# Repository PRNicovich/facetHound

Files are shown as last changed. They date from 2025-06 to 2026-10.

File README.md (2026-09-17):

# Facet Hound

Open hardware and software for the Facet Hound digital lapidary faceting machine.

Facet Hound is a mast-style faceting machine with digital readouts on all three axes, electronic indexing precise to less than 0.01 degrees, and a direct-driven lap powered by a brushless DC motor. It is designed to be replicated with readily available components and a minimum of custom parts. In 2025, the included components cost approximately $1,600.

Complete v7 and v8 assemblies are included as `Hardware/FacetHoundv7.step` and `Hardware/FacetHoundv8.step`. Subfolders of `Hardware/` contain vendor files for machining (`.step`, `.pdf`), 3D printing (`.stl`), PCB fabrication (`.brd`), and laser/plasma/waterjet cutting (`.dxf`). Commercially available parts are identified in the main design.

Subfolders of `Software/` contain the Arduino C++ sketches and desktop Python tools. The main module is a Raspberry Pi Pico 2, while peripheral controllers use RP2040 Zero boards.

## Current firmware

The current Pico 2 base plus RP2040 Zero mast, display, and keyboard-host
release is in
[`Software/FacetHound_SD_Loader`](Software/FacetHound_SD_Loader). It includes:

- Classic, Dynamic, and Static HX8357D display modes.
- A twist-wheel settings UI for machine and display configuration.
- Persistent CW/CCW indexing, Table Adapter, servo, calibration, and axis settings.
- Variable-length mark points with direct numeric editing.
- GemCad `.asc` and Facet Hound `.fct` loading from microSD.
- Source-validated `.fhc` geometry caching and a PC bulk converter.
- Runtime convex-gem mesh generation on the Pico 2 and streaming to the display.
- A documented USB CDC API and PC diagnostic/motion-test console.
- Matching streaming mast telemetry for tip, index, and force sensing.
- A dedicated PIO-USB keyboard host with the matching UART key protocol.

See the [release README](Software/FacetHound_SD_Loader/README.md) for SD wiring, dependencies, flashing instructions, limits, and verification results.

## Repository map

- `Hardware/`: complete assemblies and fabrication files.
- `Software/FacetHound_SD_Loader/`: current four-controller firmware release.
- `Software/caseModule/` and `displayModule/`: earlier module sketches.
- `Software/gemUtils/`: GemCad parsing, display prototypes, and geometry utilities.
- `Software/engraveUtils/`: engraving experiments.

These designs remain preliminary and may contain incomplete or untested elements. Contributions and bug fixes are welcome as pull requests.

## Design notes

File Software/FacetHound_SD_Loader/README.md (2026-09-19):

# Facet Hound SD loader build

This package contains the matching base, mast, display, and USB keyboard-host
firmware for loading GemCad designs from a microSD card through Display
Settings and operating the Facet Hound hardware as one system.

## Source targets

The complete Arduino sources are in `baseChassisModule/` for the Raspberry Pi
Pico 2 base, `mastModule/` for the Waveshare RP2040 Zero sensor module, and
`displayModule_v6_gem/` for the Waveshare RP2040 Zero display with the existing
HX8357D wiring. The dedicated keyboard host is in `usbToUART/`. Build and board
settings for all four controllers are collected in `FLASHING.md`.

See `INTEGRATION_TEST.md` for the staged three-module bring-up procedure and
short-circuit isolation checklist. The mast's exact UART contract and sensor
ranges are documented in `mastModule/README.md`.

## SD hookup

| microSD reader | Base GPIO |
| --- | ---: |
| CS | 10 |
| MOSI | 11 |
| SCK | 12 |
| MISO | 13 |

This is the connector order routed by `Hardware/pcb/v9/BaseModule.sch`.
Because it is not a legal hardware-SPI mapping, the firmware
uses Arduino-Pico's PIO-backed `SoftwareSPI`. The active motor link uses GPIO
8/9 at the v9 `ESC.TTL` header and an external automatic-direction RS-485
module; GPIO 26/27 are not routed on the v9 board.

Use a FAT16/FAT32 card. Put `.asc` or `.fct` files in its root, insert it, then
open **Settings -> Load SD design**. Scroll with the twist wheel and click to
load. The existing next/previous mark controls then walk the file's cuts in
GemCad order and home the index axis to the selected cut.

On first load the base looks for a same-named `.fhc` geometry cache. A cache is
used only when its format version, source byte count, and source CRC32 match.
Otherwise the Pico rebuilds the geometry and writes a fresh cache beside the
source. For example, `round.asc` produces `round.fhc`. Prebuild one file or a
whole folder on a PC with `tools/bulk_convert_gems.py` so the Pico only needs to
validate and load the cache.

Classic mode shows `T<tier> F<facet>`, signed target angle, and index in the
mark row. Dynamic/static gem modes show the loaded title and target angle/index
in the header/HUD. The first imported GemCad name in a tier is propagated to
all of that tier's facets, so labels such as `C1`, `C2`, `P1`, and `G2` remain
beside the tip angle throughout the tier; an unnamed table cut is shown as `T`.
GemCad center-to-facet distance is used only as the plane equation distance
during mesh construction; it is not machine Z and is never shown or commanded
as a Z target.

Without an SD design, Dynamic and Static navigate the built-in display gem.
The base carries its compact facet-pose table and sends an exact `@JOB` record,
so keyboard tier/facet changes select the target face instead of inferring a
face from the current encoder pose. Facets advance by increasing machine index
within each tier; tier changes begin at that tier's lowest index.

The Pico 2 now rebuilds the loaded design's 3D wireframe by incrementally
clipping a convex mesh against the GemCad half-space planes, then streams it to
both dynamic and static display modes. Redundant planes are skipped without
testing plane triples, and an adaptive temporary cube is never retained in the
result. The compiled `gem_data.h` design remains only as a startup/failure
fallback. Geometry is bounded at 512 planes, 1,024 vertices, and 2,048 edges.
Loading still does not command mast or Z motion; index selection uses the
existing twist control and safety behavior.

Settings also now includes encoder-zero actions (index, tip, Z, or all), Z-axis
polarity, flow conversion calibration in mL/min per raw flow tick, and a Special
Commands page for signed 0.01-10 RPM constant index spin. Spin stops on page
exit and times out if the display keepalive disappears.

See `baseChassisModule/SD_GEM_LOADER.md` for the parser behavior, cache format,
`.fct` coordinate format, limits, and serial protocol. See
`baseChassisModule/BASE_WIRING_AND_TEST.md` for the full pin map, dedicated
keyboard UART, and USB CDC bench console. The underlying PC control protocol is
documented in `baseChassisModule/PC_USB_API.md` so future software can drive the
base directly without depending on the supplied console UI.

## Verification

- Base source compiled with Arduino-Pico 5.6.0 for Raspberry Pi Pico 2:
  172,876 bytes flash; 16,392 bytes static RAM.
- Mast source compiled with Arduino-Pico 5.6.0 for Waveshare RP2040 Zero:
  60,972 bytes flash; 9,672 bytes static RAM.
- Keyboard USB-host source compiled with Arduino-Pico 5.6.0 for Waveshare
  RP2040 Zero at 240 MHz, `-O`, and Adafruit TinyUSB: 90,308 bytes flash;
  33,004 bytes static RAM.
- Display source compiled with Arduino-Pico 5.6.0 and the existing HX8357D
  flags: 392,832 bytes flash; 29,228 bytes static RAM.
- The reference `gemLoader.py` was exercised against nine supplied ASC
  fixtures (22 to 240 cuts; 64/80/96 wheels), including continuation lines,
  fractional indexes, and named facets.
- The double-precision convex-clipper mirror reproduced all nine reference
  fixtures exactly in topology. The largest had 240 planes, 466 vertices, and
  704 edges; maximum nearest-vertex error was `3.44e-14` model units.

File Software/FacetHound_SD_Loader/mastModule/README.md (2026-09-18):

# Mast module

This is the current mast firmware packaged beside the matching
`baseChassisModule` and `displayModule_v6_gem` projects. It is built for the
Waveshare RP2040 Zero with the Arduino-Pico core and the `RunningAverage`
library.

## Pin map

| Function | Mast GPIO |
|---|---:|
| Force sensor analog input | 28 |
| Tip encoder CS / DATA / CLOCK | 14 / 12 / 13 |
| Twist encoder CS / DATA / CLOCK | 15 / 7 / 6 |
| UART TX to base | 8 |
| UART RX from base | 9 |

The UART is 3.3 V TTL at 115200 baud. Connect mast TX GPIO8 to base RX GPIO2,
mast RX GPIO9 to base TX GPIO3, and connect grounds. Do not connect either UART
signal to RS-232 voltage levels.

## Base protocol compatibility

The current base consumes newline-terminated ASCII records:

```text
@tip,47850
@twist,2048
@force,3200
```

The mast reports every 20 ms. A received `?` also requests an immediate snapshot.
`@encfault` is a bit mask: 0 = both checksums good, 1 = tip invalid,
2 = index invalid, 3 = both invalid. Invalid encoder readings are omitted;
old averaged values are not reissued as fresh feedback. The base disarms
index lock on invalid index feedback. `encoder_fault=-1` in base STATUS means
the mast has not yet supplied this health record.

After upgrading from the legacy tip decoder, re-zero the tip at a known
reference: the old decoder included checksum bits in its position value.

The immediate snapshot preserves compatibility with the older polling base.
The active base does not need to poll.

| Record | Mast range | Base expectation | Result |
|---|---:|---:|---|
| `@tip` | 0-131064 | 131072 counts/revolution | Compatible |
| `@twist` | 0-4095 | 4096 counts/revolution | Compatible |
| `@force` | 0-131040 | accepted through 140000 | Compatible |

Twist uses a circular average, so samples around the 4095/0 boundary do not
average incorrectly through the middle of the wheel. Tip and force retain the
classic oversampled ranges used by existing calibration values. The machine
UART does not depend on USB. Telemetry is also mirrored to USB only when the
mast's USB CDC port is actively open during boot; USB power by itself does not
enable diagnostic mirroring.

The AMT23 SSI response begins with two parity/check bits. The 14-bit tip
position is taken from the low 14 bits before being scaled by eight for the
legacy base-module range. The 12-bit twist position is shifted right by two
because that mode supplies two low padding bits.

The firmware does not wait for any sensor to identify itself. With sensors
unplugged it continues sending frames, although the floating input values are
not meaningful. This permits UART integration testing before installing the
sensors.

The obsolete mast protocol used space-delimited `i`, `l`, and `e` records only
after receiving `?`. That format is not accepted by the current base and is no
longer emitted.

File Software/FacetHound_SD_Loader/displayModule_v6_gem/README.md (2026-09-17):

# Facet Hound RP2040 display v6

This Arduino-Pico firmware runs the 320 x 480 HX8357D display on the legacy
RP2040 Zero wiring. It provides three persisted boot modes:

- `CLASSIC`: the original machine-status UI and custom fonts.
- `DYNAMIC`: a smoothly animated gem wireframe driven by live machine pose.
- `STATIC`: TOP, BOTTOM, FRONT, and SIDE gem diagrams.

The firmware listens to the instrument UART and USB CDC simultaneously. Both
use the existing newline-delimited `@KEY,value` protocol, so the USB connection
is also the proxy/test input; no alternate firmware image is necessary.

The instrument UART uses a 512-byte receive queue so rendering cannot discard
short bursts from the base. Before normal telemetry begins, the base sends
`@PING,BASE`; the display answers `@PONG,BASE` to prove both UART directions.

When the display's own USB CDC port is open during boot, it begins with a
roughly 3.3-second animated splash. An installed display without an active USB
session goes directly to its persisted UI. The compiled
fallback gem is shown as a neutral, depth-cued wireframe at the C1 mast angle
and rotates at constant index speed. After about 0.9 seconds, the colored
`FACET HOUND` title fades in over the gem and remains for about 2.4 seconds
while rotation continues. A small centered
`A product of Advanced Precision Technologies, LLC` credit accompanies the
title at the bottom; the selected persisted UI then starts normally.

A transient settings menu overlays any of the three screens. It currently edits
display mode and is structured for later base-module settings.

## Hardware and Arduino setup

Use Earle F. Philhower's **Arduino-Pico** core and install:

- TFT_eSPI
- PioEncoder

`SerialPIO` is supplied by Arduino-Pico. Select the RP2040 Zero-compatible
board definition and use the normal 133 MHz CPU setting initially.

The legacy pin assignment is unchanged:

| Function | GPIO |
| --- | ---: |
| TFT SCLK | 2 |
| TFT MOSI | 3 |
| TFT CS | 5 |
| TFT DC | 6 |
| TFT RESET | 7 |
| Instrument UART TX | 8 |
| Instrument UART RX | 9 |
| Encoder | 10 |

TFT_eSPI compiles its driver configuration as part of the library, rather than
from the sketch. Back up the library's current `User_Setup.h`, then use
`User_Setup_HX8357D_RP2040.h` from this directory as its setup. It selects the
HX8357D driver, these pins, and the proven 62.5 MHz SPI setting.

Open `displayModule_v6_gem.ino` in Arduino IDE and upload it. The first boot
uses `CLASSIC`; later selections are stored in flash.

The packaged project also includes `displayModule_v6_gem_HX8357D.uf2`, already
compiled for the Waveshare RP2040 Zero with the exact HX8357D settings above.
To use it, hold BOOT while connecting/resetting the RP2040, then copy the UF2
onto the `RPI-RP2` drive. Building from source is preferable after changing the
embedded gem or UI.

## Select a screen

Send one of these commands through either the instrument UART at 460800 baud or
the USB serial port:

```text
@MODE,CLASSIC
@MODE,DYNAMIC
@MODE,STATIC
```

A changed mode is committed to flash and the RP2040 reboots. Query the current
mode without rebooting with:

```text
@MODE,?
```

Numeric aliases `0`, `1`, and `2` mean classic, dynamic, and static.

## Settings menu

Open the menu and navigate it through either serial connection:

```text
@MENU,TOGGLE
@MENUKEY,UP
@MENUKEY,DOWN
@MENUKEY,SELECT
@MENUKEY,BACK
```

The menu asks the base for one settings snapshot with `@CFGGET,ALL` when it
opens. Edits use `@CFGSET,id,value` or `@CFGACTION,id,value`, followed by a base
reply. Settings do not stream continuously. Long mark-point lists are fetched
in eight-value pages while that screen is visible. See `SETTINGS_PROTOCOL.md`
for the implemented base-module contract and physical control mapping.

The settings UI includes display mode, CW/CCW index direction, Table Adapter
(subtracts 45 degrees from the reported tip angle), automatic servo enable,
wheel index, Z polarity, flow conversion calibration, encoder-zero actions,
Special Commands with constant index spin, reset spacing, an SD design browser,
and direct numeric editing of a variable-length mark-point list. The card is attached to the base module;
the display requests six-name pages and loads a selected `.asc` or `.fct` file
through the settings protocol.

## USB proxy/testing

Install pyserial on the laptop:

```powershell
py -m pip install pyserial
```

Run animated test telemetry (replace `COM7`):

```powershell
py usb_proxy_test.py COM7 --demo 30
```

Change mode:

```powershell
py usb_proxy_test.py COM7 --mode dynamic
```

Or start an interactive protocol terminal:

```powershell
py usb_proxy_test.py COM7
```

The display sends encoder updates to both outputs as `@ZENC,count`.

For a visual test that runs directly in Spyder, open and run
`settings_menu_spyder.py`. It uses Matplotlib and can run with or without serial
hardware. `SERIAL_PORT = "AUTO"` selects a lone RP2040/USB serial device; replace
it with an explicit value such as `"COM5"` if several ports are connected, or
use `None` for a local-only preview. It now mirrors every firmware settings page. Arrow keys emulate
twist-wheel rotation, Enter is wheel click, Backspace is the top-left key,
`F`/`C` change edit tier, Delete removes a mark point, and `M` opens/closes the
menu. Press `D` or click **LIVE DEMO** to close Settings and stream moving
tip/index/Z telemetry so Dynamic mode visibly animates.

## Replace the embedded gem

`gem_data.h` contains the startup fallback mesh. When the base loads an ASC/FCT
design, the Pico 2 calculates the convex solid and streams its vertices, edges,
and facet ownership to this display. Dynamic mode rotates those runtime 3D
vertices; static mode projects the same runtime vertices into its four panels.

From a checkout containing `gemUtils/gem_generator.py`, run:

```powershell
py export_gem_data.py path\to\design.asc gem_data.h --gem-utils path\to\gemUtils
```

Rebuild and upload the sketch after regenerating the fallback header. The
supplied fallback was generated from `pc01391.asc` (`PC 01.391 Rings of Fire`).

Runtime SD jobs replace the displayed wireframe after a complete mesh transfer,
as well as replacing the machine cut sequence. GemCad center-to-facet distance
is used as a plane equation term during geometry construction, but it remains
unrelated to machine Z and is not shown as a Z target.

GemCad `n` names are treated as tier labels: the first name found in a tier is
shown for every facet in that tier (`C1`, `C2`, `P1`, `G2`, and so on). With a
runtime wireframe loaded, the large tip value is the tier target and the small
value is live tip error. Unnamed tiers are inferred as table, crown, pavilion,
or girdle from their geometry. Static view edges and the moving wireframe use
depth cueing; the lower HUD uses direction, RPM-unit, and flow-unit icons.

## Protocol mapping used by gem modes

- `T`: target index position.
- `E`: signed index error; live index is reconstructed as `T + E`.
- `TIP`: live tilt angle.
- `WIDX`: machine index-wheel resolution (normalized to the active runtime or
  fallback design).
- `ZMM`, `RPM`, `RPV`, `DIR`, `FLW`, `FLD`, and force `F`/`N`: lower HUD.

The large RPM readout shows the commanded setpoint while the lap is paused and
the measured `RPV` value while it is running. Flow is a commanded/calibrated
setpoint because the current hardware has no independent flow-rate sensor.

All other legacy fields continue to be parsed for classic mode.

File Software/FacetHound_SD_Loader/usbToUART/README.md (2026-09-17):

# USB keyboard-to-UART module

This dedicated RP2040 Zero module is the machine's USB host for the physical
keyboard. It keeps USB host behavior off the base Pico and translates new HID
key presses into the base module's simple 3.3 V UART protocol.

## Wiring

| Function | Bridge GPIO | Connects to |
|---|---:|---|
| PIO USB host D+ | 2 | Keyboard USB D+ |
| PIO USB host D- | 3 | Keyboard USB D- |
| UART TX | 0 | Base keyboard RX GPIO6 |
| UART RX | 1 | Base keyboard TX GPIO7 |
| Ground | GND | Base and keyboard-supply ground |

The keyboard also needs a correctly protected 5 V VBUS supply from the host
hardware. D+/D- are not power pins. Confirm VBUS polarity, grounding, current
protection, and the PCB's USB connector orientation before attaching a keyboard.
The UART side is 3.3 V TTL at 115200 baud, not RS-232.

## UART protocol

Each newly pressed HID usage is emitted on its own newline-terminated record:

```text
D,4
D,17
```

The active base consumes this format directly in `keyboardTask()`. Releases
are not sent. Already-held keys are suppressed when another key changes, and a
multi-key report produces one record for each newly pressed key. Non-keyboard
HID interfaces are ignored without stalling the USB host endpoint.

The bridge also emits an idle health record once per second while its USB-host
core is responsive:

```text
@HELLO,KEYBOARD
```

The base consumes this internally and reports `keyboard_link=up`; it never
treats the heartbeat as a key press.

The physical layout and HID assignments are in
[keyboardSettings.png](keyboardSettings.png). Operator functions are mapped in
[`../baseChassisModule/KEYBOARD_MAP.md`](../baseChassisModule/KEYBOARD_MAP.md).

## Required Arduino settings

Use Arduino-Pico 5.6.0 with these board selections:

| Setting | Value |
|---|---|
| Board | Waveshare RP2040 Zero |
| CPU speed | 240 MHz (Overclock) |
| Optimize | Optimize (`-O`) |
| USB stack | Adafruit TinyUSB |
| Flash | 2 MB, no filesystem |

The PIO USB host was originally validated with the 240 MHz and `-O` settings;
do not silently substitute the board defaults. The firmware uses core 1 for
the host task and restarts that core if its heartbeat stops for three seconds.

Verified Arduino CLI target:

```text
rp2040:rp2040:waveshare_rp2040_zero:freq=240,opt=Optimize,usbstack=tinyusb
```

Current compile size: 90,308 bytes flash and 33,004 bytes static RAM.

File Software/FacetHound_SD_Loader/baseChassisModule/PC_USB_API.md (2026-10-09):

# Base-module PC USB API

The base firmware exposes a line-oriented control and telemetry API over the
Pico's native USB CDC serial port. `tools/base_module_console.py` is a reference
client, not a required intermediary: another PC program can open the same COM
port and send these commands directly.

This API is separate from the dedicated keyboard UART on GPIO 6/7 and from the
base-to-display UART. Using USB CDC does not reconfigure either hardware link.

At startup the base probes the display on the unchanged TX5/RX4 pins, first at
uiReno's 38400 baud, then at 460800 for installed fast-display firmware. Each
rate gets a 3-second window with an existing `@PING,<token>` probe every 250 ms.
Only the matching `@PONG,<token>` confirms the rate; received byte counts and
unsolicited messages do not. USB reports `@DISPLAY_LINK,TRY,baud=...` and
`@DISPLAY_LINK,READY,baud=...`. Saved-gem restoration and model transmission wait
for confirmation. Probing repeats if neither rate answers, but never changes
the rate after confirmation. Mast/keyboard ports and display firmware are not
reconfigured. Continued TRY messages mean no round trip at either supported
rate, not a geometry-parser failure.

Restoring the saved gem does not rewrite its already-saved SD selection marker;
new selections still save normally. After loading, three bounded PING attempts
test the existing link before model metadata/cache/mesh transmission. USB reports
`@GEM,POSTLOAD_PING_OK` or `@GEM,DISPLAY_ERROR,POSTLOAD_PING_TIMEOUT`.
No UART resets or baud changes occur during this post-load test.

## Transport and framing

- USB CDC serial, conventionally opened as 115200 baud, 8-N-1. USB CDC does
  not physically depend on that baud rate, but clients should use 115200 for
  consistency with the supplied console.
- Commands and responses are printable ASCII terminated by `\n`.
- The firmware accepts `\r\n` and ignores `\r`.
- Commands are case-insensitive and fields are separated by spaces.
- Maximum accepted command line is 127 bytes, excluding the terminator.
- Replies beginning with `@ACK` indicate acceptance, `@ERR` indicates a bad
  command or argument, and `@STATE` / `@IO` are telemetry.

The port also carries boot diagnostics, cache messages, and asynchronous
`@KEY,<hid>` records. Clients should therefore parse by prefix and ignore
unknown lines for forward compatibility.

## Commands

| Command | Meaning | Typical reply |
|---|---|---|
| `HELP` | List commands supported by the running firmware | One or more `@HELP,...` lines |
| `STATUS` | Emit one complete state and I/O snapshot | `@STATE,...` then `@IO,...` |
| `LINKCHECK` | Two receive-path snapshots one second apart, without restarting UARTs or consuming their input | `@LINKCHECK`, `@RXCHECK`, `@RXPIO` |
| `STREAM ON [ms]` | Stream snapshots every 50-5000 ms; default 250 ms | `@ACK,STREAM,ON` |
| `STREAM OFF` | Stop periodic snapshots | `@ACK,STREAM,OFF` |
| `PROBE` | Immediately query the mast, display, and lap Modbus links | `@ACK,PROBE,MAST_DISPLAY_AND_LAP` |
| `TRACE ON` / `TRACE OFF` | Mirror complete incoming peripheral UART lines to PC USB | `@ACK,TRACE,ON/OFF` |
| `TEST DISPLAY ON` | Send changing synthetic values to the display without changing machine state | `@ACK,TEST,DISPLAY,ON` |
| `TEST DISPLAY OFF` | Restore normal machine telemetry | `@ACK,TEST,DISPLAY,OFF` |
| `TEST DISPLAY LOOPBACK` | Five-second base GPIO4/5 loopback test | `@ACK,TEST,DISPLAY,LOOPBACK,5_SECONDS` |
| `KEY <0..255>` | Inject one configured HID usage through the same action router as the UART keyboard | `@ACK,KEY,<hid>` |
| `JOG TWIST <index-units>` | Set a relative index target and enable index lock | `@ACK,JOG,TWIST,<target>` |
| `INDEX PROBE` | Explicit motion test: 128 positive STEP pulses at 300 pulses/s maximum, then sample encoder delta and release; requires fresh valid encoders, axes unlocked and lap paused | `@INDEX_PROBE,...,suggested_motor_sign=...` (does not change calibration) |
| `JOG Z <signed-steps>` | Request a relative Z move in raw motor steps | `@ACK,JOG,Z,<steps>` |
| `RPM <0..1500>` | Set lap-speed command in RPM (no automatic startup boost) | `@ACK,RPM,<rpm>` |
| `MOTOR CW` | Set lap direction clockwise | `@ACK,MOTOR` |
| `MOTOR CCW` | Set lap direction counter-clockwise | `@ACK,MOTOR` |
| `MOTOR OFF` | Set lap RPM command to zero | `@ACK,MOTOR` |
| `MOTOR PROBE` | Queue a non-motion Modbus read of lap fault/status | `@ACK,MOTOR,PROBE` |
| `MOTOR DEMOPROBE` | One read-only status request using the exact uiReno BLD510B library; stop motion and unlock Z first | `@ACK,MOTOR,DEMOPROBE`, then `@BLD_DEMO,ok=...,error=...,fault=...,run=...` |
| `MOTOR LOOPBACK` | Adapter disconnected, GP8 TX jumpered to GP9 RX; lap paused and index/Z unlocked; see `../INTEGRATION_ENCODER_BLD.md` | `@BLD_LOOPBACK,match=0/1,rx_bytes=...,hex=...` |
| `MOTOR STATUS` | Report Modbus validation counters and last raw reply | `@MOTOR,...` |
| `SD STATUS` | Report SD initialization and root-directory state | `@SD,...` |
| `SD PROBE` | With axes unlocked and lap paused, test CMD0 and initialization, then use SdFat for card initialization, sector-0 read and volume mounting. No formatting/file writes; follow with SD RETRY | `@SD_PROBE,...`, `@SD_INIT,...`, `@SD_FS,...` including library error/data codes |
| `SD RETRY` | With axes unlocked and lap paused, force SD reinitialization after insertion/wiring changes | `@SD_MOUNT,bus=gpio,...`, `@ACK,SD,RETRY,READY/MISSING` |
| `SD LIST` | List folders and `.asc`, `.gem`, `.gcs`, `.fct` files in the current directory | `@SD_DIR,<path>`, `@SD_FILE,<index>,<name>`, `@SD_TYPE,<index>,DIR/FILE` |
| `SD UP` | Go to the parent directory; root stays root. Rejected while a gem load is pending | `@SD_DIR,<path>` and refreshed display browser |
| `GEM LOAD <index>` | Load the index returned by SD LIST; axes unlocked and lap paused. Builds geometry or reads cache, then transfers it asynchronously | `@GEM,LOADED,<path>`, `@GEM,GEOMETRY,<cache-status>,vertices=...,edges=...,planes=...`, then `@GEM,DISPLAY_READY` or `@GEM,DISPLAY_ERROR,...` |
| `MODE CLASSIC\|STATIC\|DYNAMIC` | Select display mode without changing motor locks | `@ACK,MODE,<mode>` |
| `FLOW <0..750>` | Set raw pump velocity; displayed mL/min uses the configured conversion | `@ACK,FLOW,<value>` |
| `PUMP FWD` | Set forward pump direction | `@ACK,PUMP` |
| `PUMP REV` | Set reverse pump direction | `@ACK,PUMP` |
| `PUMP OFF` | Stop the pump direction command | `@ACK,PUMP` |
| `STOP` | Stop index, Z, lap, and pump commands | `@ACK,STOP` |

`GEM LOAD <index>` enters a folder when the selected SD LIST entry is a directory;
it does not start motion. Run `SD LIST` again after entering or leaving a folder.
Indices are relative to the current directory, shared with the display browser.
Native binary GEM support and limits: [GEM_AND_FOLDERS.md](../GEM_AND_FOLDERS.md).

Entry **0** is now always the built-in gem, even without an SD card. Disk entries
start at 1; refresh `SD LIST` instead of reusing indices from older firmware.
`GEM LOAD 0` cancels failed saved-design recovery, unlocks index/Z, restores the
built-in mesh/targets and writes the built-in selection when a card is available.

Malformed values receive a specific `@ERR,<command>,<reason>` reply. Unknown
commands receive `@ERR,UNKNOWN,use HELP`.

`KEY` uses the HID usages in [KEYBOARD_MAP.md](KEYBOARD_MAP.md). For example,
`KEY 4` opens Settings, `KEY 5` selects the next loaded gem tier, and `KEY 6`
selects the previous tier. Menu suppression and menu-specific key meanings are
identical to the physical UART keyboard path.

## State telemetry

### Receive-path diagnosis

`LINKCHECK` identifies diagnostic build `20261009-RX-WRAP-FIX` and the actual
Arduino-Pico core version used for compilation. It reports mast-task invocation
and byte counters, then the non-consuming `available()`/`peek()` results for
mast, display and lap. PIO records include the matching input state machine,
enable flag, hardware RX FIFO level, RX interrupt-source enable, NVIC enable,
program counter, current instruction, divider and configuration registers.
These are snapshots, not a wire capture; a high RX pin alone does not prove an
idle wire. Snapshot printing can allow further input to arrive.

The command does not change baud, pins, PIO programs, interrupt enables, queue
contents, or motor commands. The ordinary loop runs between snapshots. It does
not clear the overflow latch; `STATUS` remains the command that reads/clears it.

For frozen mast values with a repeatedly set overflow flag, compare both
snapshots: rising task calls with frozen byte count rules out a missing loop
invocation. `queued=0` with `peek>=0` exposes inconsistent queue API results.
A nonempty hardware FIFO with its interrupt source/NVIC disabled identifies a
different receiver failure. Neither an empty FIFO nor these logs alone proves
that valid bytes are present on the wire. Do not reset the port before taking
the snapshots, because that would erase the failure state.

The October 9 capture on core 4.5.2 demonstrated `queued=0,peek=64` repeatedly
on the mast, while the main loop and PIO receiver remained active. That core's
`available()` uses unsigned `(writer-reader) % fifoSize`. SerialPIO allocates
one more entry than the requested capacity. The former 256-byte request thus
allocated 257 entries; a wrapped full buffer produced `0xffffffff % 257 == 0`,
so the parser never drained it and all further input overflowed. Requests are
now 255 for mast/display, 127 for keyboard and 31 for lap, making the actual
allocations powers of two. This fixes the wrap calculation without changing
pins, baud rates, parsers or PIO programs, and also works on newer cores.

Separately, core 4.5.3 includes upstream SerialPIO RX edge/sampling fix #2929.
The queue-size correction does not include that sampling fix and does not
claim to resolve the lap's CRC errors. See the upstream
[4.5.3 release](https://github.com/earlephilhower/arduino-pico/releases/tag/4.5.3)
and [receiver fix](https://github.com/earlephilhower/arduino-pico/pull/2929).

`@STATE` is a comma-separated set of `name=value` fields:

```text
@STATE,123456,tip=42.500,target=12.0000,actual=11.9980,error=0.0020,z_mm=1.2500,rpm_set=20,rpm_actual=19,flow=100.00,force=514.0,twist_lock=1,z_lock=0,motor_dir=1,flow_dir=2,mark=3/96,sd=ready,gem=round.asc
```

The second field is milliseconds since boot. Fields may be added later, so a
client should read values by name rather than fixed column position.

| Field | Meaning |
|---|---|
| `tip` | Actual calibrated tip angle in degrees |
| `target` | Target index in current wheel units |
| `actual` | Actual index in current wheel units |
| `error` | Current signed index error |
| `z_mm` | Actual Z position in millimetres |
| `rpm_set` / `rpm_actual` | Commanded and reported lap RPM |
| `flow` | Raw pump setpoint; not converted mL/min |
| `force` | Current raw force reading |
| `twist_lock` / `z_lock` | Axis lock state, `0` or `1` |
| `motor_dir` / `flow_dir` | Internal direction state |
| `mark` | One-based selected mark and total mark count |
| `sd` | `ready` or `missing` |
| `gem` | Active source filename or `none` |

The following `@IO` record contains cumulative received-byte counters:

```text
@IO,mast_rx=1234,mast_link=up,mast_age_ms=4,key_rx=37,keyboard_link=up,keyboard_age_ms=183,display_rx=8912,display_link=up,display_age_ms=237,usb_rx=44
```

`mast_link=up` requires a valid `tip`, `twist`, or `force` protocol record in
the last 3.5 seconds; random bytes do not count. The deliberately generous
integration timeout also supports older mast firmware that answers the base's
periodic `?` poll instead of streaming continuously. `mast_age_ms` is the time
since the last valid mast record (`0` means none has ever arrived).

The keyboard bridge publishes an idle health record once per second while its
USB-host core is responsive. `keyboard_link` uses a 2.5-second timeout, so the
link can be verified without pressing a key. Actual presses still produce the
asynchronous `@KEY,<hid>` record.

The display sends an idle heartbeat once per second, so `display_rx` increases
even when its encoder is stationary. `display_link` is `up` when a byte arrived
from the display in the last 2.5 seconds; `display_age_ms` is the time since the
most recent byte (`0` means none has ever arrived).

`display_roundtrip=up` is the stronger display test. The base sends
`@PING,BASE` and requires the display to echo `@PONG,BASE`, proving that both
UART directions and the display parser work. `display_link=up` with
`display_roundtrip=down` means only display-to-base has been proven.
An explicit `TEST DISPLAY ON` bypasses the handshake gate so it can test the
base-to-display direction even when the display-to-base direction is dead.

Display telemetry is serialized as one short protocol record every 10 ms.
This avoids overflowing the display controller's 32-byte SerialPIO receive
FIFO while it is rendering; older base builds sent the entire screen as one
large burst and could appear one-way even with correct wiring.

The base now uses larger receive queues and sends only `@PING,BASE` until a valid
display reply establishes the round trip. Normal or synthetic screen telemetry
does not start on a one-way link. `rx_overflow=MxKxDx` reports and clears each
SerialPIO overflow latch whenever `STATUS` is emitted.

For a base-side electrical loopback, power down, disconnect the display cable,
and jumper only signal pins 2 and 3 of the base `DISPLAY` connector. Do not
jumper either power pin. Power the base from USB, send
`TEST DISPLAY LOOPBACK`, then `STATUS` within five seconds. A
`display_loopback=up` result proves base GPIO5 TX, GPIO4 RX, and the base UART
software; the fault is then beyond the base connector.

`rx_levels=M1K1D1` reports the instantaneous mast, keyboard, and display RX pin
levels. UART idle is normally high (`1`); a persistent zero suggests a short,
unpowered transmitter, or incorrect connector mapping. `uart_map` reports the
compiled mast and keyboard trial mapping.

For a base-only pin-direction trial, change `MAST_UART_SWAP_TRIAL` or
`KEYBOARD_UART_SWAP_TRIAL` at the top of `baseChassisModule.ino`, then upload
only the base. Leave both `false` for the documented v8 wiring. Set only one at
a time so the result is unambiguous.

`@MOTOR` distinguishes a stopped motor from a dead Modbus link. `lap=up`
requires a correctly addressed, CRC-valid reply within 1.5 seconds. The record
also reports transmit count, received bytes, timeouts, CRC failures, Modbus
exceptions, and the last reply in hexadecimal. `lap_uart=pio` confirms the
BLD-510B is on the proven GP8/GP9 SerialPIO link; `tmc_uart=setup_only` describes
the three on-board stepper-driver configuration links; it is not the lap-motor
RS-485 link.

`@SD` reports card initialization attempts separately from root-directory
readability. STATUS, STREAM and settings readiness queries use cached state;
they never retry card initialization. After inserting a card use `SD RETRY`.
Explicit file operations can also attempt initialization, throttled to once
per second while the card is missing. These operations can block on SD timeouts.

`@KEY,<hid>` is emitted whenever a key arrives from the physical keyboard
UART. It allows a PC supervisory application to observe operator input without
intercepting the keyboard connection.

## Control guidance

- Send `STATUS` after connecting instead of assuming previous machine state.
- Treat jog acknowledgements as command acceptance, not proof that motion has
  completed; observe `actual`, `target`, and `error` in subsequent telemetry.
- Send `STOP` on application shutdown, communications failure, or operator
  abort. A physical power cutoff remains the authoritative safety mechanism.
- Only one PC process should own the USB CDC port at a time.
- Ignore response prefixes and fields that the client does not recognize.
- Do not use this diagnostic/control API as a hard real-time motion bus.

## Minimal Python example

```python
import serial

with serial.Serial("COM5", 115200, timeout=1) as base:
    base.write(b"STATUS\n")
    print(base.readline().decode("ascii", "replace").strip())
    print(base.readline().decode("ascii", "replace").strip())

    base.write(b"JOG TWIST 1\n")
    print(base.readline().decode("ascii", "replace").strip())

    base.write(b"STOP\n")
```

## Lap startup and diagnostics

The keyboard speed knob changes the saved/user setpoint by 5 RPM per detent.
On an explicit start with a positive setpoint below 300 RPM, the controller is
temporarily commanded to 300 RPM for 2.5 seconds after its enable-write ACK,
then returns to the setpoint. This includes the existing two-second ramp.
An absolute five-second limit from the start request also bounds the boost if
ACKs are lost. Pause/STOP cancels it; no automatic stall retries or current-limit
changes are made. A request at or above 300 RPM gets no boost.

`MOTOR STATUS`/`STATUS` includes `startup_boost`, `rpm_command_ack`,
`control_ack` (09 forward, 0B reverse, 0C brake), and the raw status `run` and
`fault` bytes. These distinguish the saved setpoint, acknowledged temporary
command, and measured speed. Command ACKs now require an exact register/value
echo, not merely any CRC-valid function-06 frame. For a direction that clicks
and stops, capture these fields before clearing the fault. A working forward
direction does not establish correct Hall/phase pairing for both directions.

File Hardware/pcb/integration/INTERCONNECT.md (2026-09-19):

# Release module interconnect

Open **ModuleInterconnect.sch** in Eagle. It is a six-sheet, electrically wired
system/harness schematic, not a PCB layout. Module symbols expose connector pad
identities and MCU GPIO functions. No legacy board routing or manufacturing ZIP
was changed. Connector numbers below are PCB pad numbers, not an assumed view
of a cable plug; the old JST library has multiple gates each with pin name `1`.

| Base v9 header/pad | Peripheral connector/pad | Signal |
|---|---|---|
| MAST 1 / 2 / 3 / 4 | Mast J1 4 / 3 / 2 / 1 | 5V / mast TX8 to base RX2 / base TX3 to mast RX9 / GND |
| DISPLAY 1 / 2 / 3 / 4 | Display J3 4 / 3 / 2 / 1 | 5V / display TX8 to base RX4 / base TX5 to display RX9 / GND |
| KEYS 1 / 2 / 3 / 4 | USBHost J2 1 / 2 / 3 / 4 | 5V / host TX0 to base RX6 / base TX7 to host RX1 / GND |
| ESC.TTL 4 / 3 / 2 / 1 | Adapter VCC / RX input / TX output / GND | 3V3 / base TX8 / base RX9 / GND |
| MICROSD 1 / 2 / 3 / 4 / 5 / 6 | SD 3V3 / CS / MOSI / CLK / MISO / GND | 3V3 / GP10 / GP11 / GP12 / GP13 / GND |

Mast/keyboard UART: 115200. Display UART: 460800. All MCU UART signals are 3.3 V.
Adapter bus terminals connect A+ to BLD A+, B- to BLD B-, with shared ground.
The adapter is automatic-direction; no DE/RE pin is driven. Terminal functions,
not adapter LEDs, wire colors, or ambiguous TX/RX silkscreen, define connections.
Do not apply 24 V to any MCU/header logic supply. BLD motor power uses its own
24 V terminals. This drawing does not prescribe motor phase/Hall colors.

## Integration modifications to preserve

- **AMT MODE disconnected:** Mast J5 pad 2 and J2 pad 2 must NOT be connected to
  the encoders' MODE leads. The v8 PCB routes these to U2 B7/B8 (MCU GP26/27);
  the as-tested cable leaves them disconnected. This is a harness change, not
  a claim that those traces have been removed from the existing PCB artwork.
- Mast J5 tip: CS pad 1 → GP14, clock pad 4 → GP13, data pad 5 → GP12, through
  U2. J2 index: CS pad 1 → GP15, clock pad 4 → GP6, data pad 5 → GP7, through U2.
  Each uses pad 6 supply and pad 3 GND. Preserve the working MODE-disconnected
  harness. The mast level shifter is not a claim that the v9 base has one.
- Display J4 Z encoder: pad 1=5V, pad 2=GND, pad 3=A→R3/R6→GP10,
  pad 4=B→R4/R5→GP11. Preserve the repaired GP11 connection. Firmware disables
  internal pulls on GP10/11; the existing dividers remain in the board schematic.
- J1/J3 pads 5–8 and J6/J2 pass-through headers on the peripheral boards are
  not UART alternatives. Their cable routing is not inferred here.

## Authoritative sources

- `../v9/BaseModule.sch` (no base level shifter).
- `../v8/MastModule_v8.sch`.
- `../v8/Display-KeyboardModule_v8.sch`.
- `../v8/USBHostModule.sch`.
- Firmware: `Software/FacetHound_SD_Loader` base, mast, display, usbToUART.

The standalone interconnect prevents accidental schematic/board mismatches in
the existing manufactured designs. XML/net connectivity can be checked without
Eagle; native Eagle visual/ERC review and power-off continuity checks remain
required before building another harness. No manufacturing sign-off is implied.

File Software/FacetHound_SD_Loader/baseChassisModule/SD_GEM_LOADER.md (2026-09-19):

# SD GemCad loader

The base module owns the microSD card and parses designs. The display only
renders the file browser and the active cut information over the existing serial
settings link.

## Wiring

The loader follows the v9 BaseModule header through `GemSdSpi`, a bounded
GPIO SPI adapter for the existing Arduino SD/SdFat filesystem:

| microSD reader | Base GPIO |
| --- | ---: |
| CS | 10 |
| MOSI | 11 |
| SCK | 12 |
| MISO | 13 |
| VCC | Reader's documented supply |
| GND | GND |

This ordering is not a legal hardware-SPI mapping. The transport clocks GPIOs
in mode 0 at no more than 250 kHz, with interrupts enabled. No PIO state
machines are allocated, including on repeated retries. The pin constants are at the top of
`sdGemLoader.h`. GPIO 8/9 serve the v9 `ESC.TTL` header for the external
BLD-510B RS-485 interface; GPIO 26/27 are not connected on v9.

The Arduino-Pico 5.6.0 `SoftwareSPI` implementation allocated another PIO
state machine on each begin, did not reclaim it on end, and waited indefinitely
for FIFO data. It also dereferenced null source/destination buffer pointers;
SdFat uses such buffers for receive-only/send-only transfers. `GemSdSpi`
avoids those paths and sends 0xFF during receive-only SD transfers. Filesystem
mounting remains in SdFat, using shared transaction mode and explicit teardown.
No formatting or installed-library modifications are required.

After uploading the base sketch, run `STOP`, `SD RETRY`, `SD LIST`.
The mount diagnostic should now say `bus=gpio`; `bus=dedicated` means the old
firmware is still running. Repeat `SD RETRY` several times and issue `STATUS`
between attempts to check that serial remains responsive. An absent card can
still take the library's finite initialization timeout. With a mounted card,
use `GEM LOAD <index>` with an index returned by `SD LIST`, then choose dynamic
mode in settings. Loading can create a same-named geometry cache (see below).

Use a FAT16/FAT32 card. Put `.asc` or `.fct` files in the card root. The browser
intentionally ignores directories and other file types.

## Geometry cache

Before rebuilding a design, the base checks for a same-named `.fhc` file on the
same card (`stone.asc` becomes `stone.fhc`). The versioned binary cache holds
the parsed cuts and complete runtime planes, vertices, and edges. Its header
stores the source file's exact byte count and CRC32, so editing or replacing the
ASC automatically invalidates stale geometry. A missing, old, malformed, or
mismatched cache is ignored safely; the normal parser and convex builder run,
then the result is saved as a replacement `.fhc` when the card is writable.

To prepare a card on a PC, use the folder converter:

```text
python tools/bulk_convert_gems.py D:\\facet-files
python tools/bulk_convert_gems.py D:\\facet-files --recursive --force
```

By default each cache is written next to its `.asc`. `--output-dir PATH` puts
the generated caches in another folder. The converter uses the repository's
existing `gemUtils/gem_generator.py`, and continues through a bulk run while
reporting any files that fail.

## GemCad `.asc`

The on-Pico parser follows `gemLoader.py`: `g` sets the wheel resolution and
meridian, the first `H` sets the title, and every `a` record supplies signed
angle, center-to-facet distance, and one or more facet indexes. A line beginning
with whitespace continues the preceding tier. Fractional indexes and `n` tier
names are supported; the first name in an `a` tier is copied to every cut in
that tier. `G` cutting instructions are ignored after parsing the coordinates.

Loading a design replaces the mark-point list with one entry per cut, in file
order. Existing next/previous mark controls therefore step through the job and
home the index axis. The display receives the active tier, facet, signed angle,
center-to-facet distance, original GemCad index, and propagated tier label. The machine
uses the angle and index. GemCad's center-to-facet distance is retained only as
source metadata: it is not a Z coordinate, is not displayed as a machine target,
and never commands the Z or mast axes.

The Pico 2 uses each distance as the `d` term of a geometric half-space plane
`n dot p <= d`. Because GemCad jobs describe convex gems, the firmware starts
with a temporary cube and clips that convex mesh by each facet plane. A plane
whose current vertices are all inside is skipped immediately. Crossing edges
create the next face directly, so the firmware never enumerates all plane
triples. If an artificial cube face survives, the cube is expanded and the
build retried; no artificial boundary is accepted into the finished mesh.

The parser accepts up to 2,048 cuts and a 383-character physical line. Runtime
geometry is deliberately bounded at 512 facet planes, 1,024 vertices, and 2,048
edges. A bad header, malformed number, geometry over those bounds, oversized
job, unbounded design, or missing card is reported without replacing the
currently loaded job. Construction work follows the size of the current convex
boundary rather than the number of possible three-plane combinations.

## Flattened `.fct` coordinate files

`.fct` is an optional, directly editable Facet Hound coordinate format:

```text
FacetHound 1
g 96 0
H Standard Round Brilliant
c 1 1 -90.0 1.02653281 93 G
c 1 2 -90.0 1.02653281 87
c 2 1 -42.5 0.61819401 93 1
```

The `c` fields are:

```text
c <tier> <facet> <signed-angle-deg> <center-to-facet-distance> <index> [name]
```

Names are single tokens. The first nonempty name in a tier is used as that
tier's label for every coordinate in the tier. Lines beginning with `#` and
blank lines are ignored.

## Display protocol

The file browser uses paged requests so neither controller stores a duplicate
directory listing:

```text
display -> base: @CFGGET,SD_FILES,0,6
base -> display: @CFG,SD_STATUS,READY
base -> display: @CFG,SD_FILE_COUNT,3
base -> display: @CFG,SD_FILE_0,round.asc

display -> base: @CFGACTION,LOAD_SD_FILE,0
base -> display: @CFGACK,LOAD_SD_FILE,Standard Round Brilliant
base -> display: @JOB,1,1,-90.0000,1.0265328,93.0000,G
base -> display: @MESHBEGIN,146,272,128,96.0000,1.0297423
base -> display: @MESHV,0,0.9419794,-0.3901806,-0.0116945
base -> display: @MESHE,0,0,1,2,0,1
base -> display: @MESHP,0,-90.00000,93.00000,1,1,G
base -> display: @MESHEND,1
```

`@JOB` retains the GemCad distance field for protocol/file fidelity, but the
display deliberately does not present it as Z. The row is refreshed when the
selected cut changes and periodically so a display reboot recovers the active
cut.

`MESHE` carries edge id, vertex A, vertex B, support count, then supporting
plane ids. `MESHP` carries plane id, angle, index, tier, facet, and the imported
GemCad tier label. The display stores edge support ids compactly instead of
allocating a 512-bit mask for every edge. A rebooted display requests the
current runtime mesh with `@CFGGET,MESH`; the compiled `gem_data.h` mesh remains
only as a fallback before an SD design is loaded.

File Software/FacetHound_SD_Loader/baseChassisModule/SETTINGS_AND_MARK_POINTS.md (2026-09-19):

# Base settings and mark points

This base firmware implements the display settings contract documented
in the display project's `SETTINGS_PROTOCOL.md`.

Notable behavior:

- Mark points are a dynamically sized `std::vector<float>` rather than a
  16-element array.
- The version-4 raw-flash record migrates version-2 and version-3 records and
  persists up to 16,320 positions in the final 64 KiB of a 2 MiB flash device.
- Index direction is persistent and changes both encoder and motor correction
  signs. A direction change stops and reacquires twist position before motion.
- Table Adapter is persistent and subtracts 45 degrees from calibrated tip.
- Automatic spin-servo enable is persistent and is controlled from the menu.
- Index, tip, Z, or all encoder readouts can be reset to zero from Settings.
  Index/tip zero offsets persist; the display-side incremental Z count is reset
  directly on the display controller.
- Z polarity and the flow display conversion (`mL/min per flow tick`) are
  persistent settings.
- Special Commands includes signed 0.01-10 RPM continuous index rotation. It
  is open-loop, suspends normal index locking, stops on page exit, and has a
  1.5-second command-lease timeout if display keepalives disappear.
- Position values are returned to the display in eight-value pages.
- SD coordinate loading uses bounded GPIO SPI on GPIO 10/11/12/13. It browses
  root-level `.asc`/`.fct` files and loads flattened cuts into the mark sequence.
- Pico 2 constructs the loaded design's convex mesh at runtime and streams up
  to 512 planes, 1,024 vertices, and 2,048 edges to the display.

See `SD_GEM_LOADER.md` for wiring, formats, limits, and the runtime protocol.

The top-level key constants in `baseChassisModule.ino` make the HID mapping
easy to change. Current menu mapping is former wheel-index/top-left = open/back
or coarser numeric tier, twist wheel = up/down, twist click = select, former
servo key = finer tier, and former cheat key = delete.

The firmware compiled successfully with Arduino-Pico 5.6.0 for the Raspberry
Pi Pico 2 base module.

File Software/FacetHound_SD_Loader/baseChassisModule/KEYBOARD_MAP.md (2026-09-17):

# Keyboard map

Facet Hound keyboard map

[`keyboardSettings.png`](../usbToUART/keyboardSettings.png) programs ordinary
HID key numbers into the dedicated
keyboard module. That module reports them to the base as `D,<usage>\n` over
the keyboard UART on GPIO 6/7 at 115200 baud. For example, physical **A** is
HID usage 4, **M** is 16, and **1** is 30. This dedicated UART connection is
intentional: **do not replace it with a Pico USB-host keyboard connection.**
The Pico's native USB port is reserved for the optional PC diagnostic console.

| Physical | HID | Normal mode | Settings mode | Firmware action |
|---|---:|---|---|---|
| A (top-left) | 4 | Open Settings | Back/close | `MENU_TOGGLE_KEY` |
| B | 5 | Next tier, lowest-index facet | Suppressed | Loaded SD gem or built-in gem navigation |
| C | 6 | Previous tier, lowest-index facet | Delete item | Loaded SD gem or built-in gem navigation |
| D | 7 | Toggle Z lock | Suppressed | `toggleZLock()` |
| E | 8 | Add mark at target index | Suppressed | `addPositionToList()` |
| F | 9 | Update selected mark | Suppressed | `updatePositionInList()` |
| G | 10 | Delete selected mark | Suppressed | `deletePositionInList()` |
| H | 11 | Offset all marks | Finer edit tier | `toggleCheatMode()` / `MENU_TIER_FINER_KEY` |
| I | 12 | Next facet/mark | Suppressed | Next higher index in the tier for gem views; next mark in Classic |
| J | 13 | Previous facet/mark | Suppressed | Next lower index in the tier for gem views; previous mark in Classic |
| K | 14 | Home selected facet/mark | Suppressed | `homeMarkPoint()` |
| L | 15 | Toggle index lock | Suppressed | `toggleTiltLock()` |
| M | 16 | Index decrement | Menu up | `changeTiltAngle()` / `MENUKEY,UP` |
| N | 17 | Cycle index step | Select | `changeTwistIndex()` / `MENUKEY,SELECT` |
| O | 18 | Index increment | Menu down | `changeTiltAngle()` / `MENUKEY,DOWN` |
| 1 | 30 | Lap RPM −1 | Suppressed | `changeMotorSpeed(-1)` |
| 2 | 31 | Lap run/pause; double-click reverses and pauses | Suppressed | `changeMotorDirection()` |
| 3 | 32 | Lap RPM +1 | Suppressed | `changeMotorSpeed(+1)` |
| 4 | 33 | Flow −1 | Suppressed | `changeFlowRate(-1)` |
| 5 | 34 | Pump run/pause | Suppressed | Immediate `changeFlowDirection(false)`; no reverse gesture |
| 6 | 35 | Flow +1 | Suppressed | `changeFlowRate(+1)` |
| 7 | 36 | Z down | Suppressed | `changeZMotorSteps(true)` |
| 8 | 37 | Cycle Z step | Suppressed | `changeZMultiplier()` |
| 9 | 38 | Z up | Suppressed | `changeZMotorSteps(false)` |

The PC diagnostic console can inject the same *firmware action* with `key A`,
`key 7`, or `KEY <hid-code>` for bench testing. That USB CDC test input is
separate from, and does not reconfigure, the keyboard UART.

When no SD design is loaded, Dynamic and Static use the display's built-in gem
as a real selectable job. The base contains the matching compact facet-pose
table, so the green face is selected from the target tier/facet rather than
guessed from the live tip encoder. Pavilion/opposite-approach targets include
the required half-wheel index offset. The display reports its mode at startup
so this behavior does not replace Classic's editable mark list.

The display owns the Settings open/closed state. The top-left key sends a
toggle request, and both sides exchange periodic menu-state checks so one lost
close packet cannot leave all machine keys suppressed. Lap double-click selects
the opposite direction in its paused state; a separate click is required to
restart. Pump control intentionally has no double-click reverse action.

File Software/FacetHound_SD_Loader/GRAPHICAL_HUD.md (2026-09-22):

# Dynamic / Static HUD update

Upload both complete sketch folders with Arduino IDE:

- `baseChassisModule/baseChassisModule.ino` — base Pico 2, using the existing board/clock settings.
- `displayModule_v6_gem/displayModule_v6_gem.ino` — display RP2040 Zero, using the existing board/clock and HX8357D settings.

No mast or USB-to-UART keyboard update is needed. Keep all companion files in each sketch folder. No wiring or motor-driver configuration changes are part of this update.

## Graphical controls

In Dynamic and Static, twist-wheel events (16/18) adjust the selected facet's temporary index cheat using the existing index step selector. H/apply-all (11) commits that adjustment to the current crown or pavilion side, across its tiers. Moving to another facet discards the temporary component. Nominal indices and geometry remain unchanged. Applied side offsets accumulate; switching between Dynamic and Static retains the temporary adjustment.

The cheat is white while temporary and cyan when applied. The displayed index is nominal; index error compares actual position with the corrected motor target. Classic controls remain unchanged.

Applied offsets are stored with the current design identity. Loading a different design clears them; this is not a multi-design persistent cheat database. State format 5 reads existing version 2/3/4 state; older firmware cannot read newly saved version 5 state. Temporary cheat is not saved.

## Views

Refresh scheduling: base telemetry rotates through all 24 fields at a 2 ms minimum slot interval (~20 Hz per field when the loop keeps up), without catch-up bursts. The graphical numeric HUD has a 33 ms minimum redraw interval; only changed 20-pixel-high strips are transmitted. Dynamic geometry is not redrawn for unrelated telemetry. These are scheduling ceilings, not measured hardware frame rates. Baud, SPI clock, and motor-control settings are unchanged.

In Dynamic and Static, the large tip number is the selected facet's nominal machine angle. Tip error text and gauge history show measured angle minus that nominal angle; the measured angle is not separately displayed. Classic modes are unchanged.

Static shows the selected tier's crown (T) or pavilion (B) cap plus a fixed side (S) projection. Each projection fits all vertices into its own bounds. Rear-facing side highlights are dark green; rear side edges are dim. The cap includes girdle edges.

Both modes share decimal-aligned values, cheat/error readouts, open-gray/filled-color lock dots and cumulative step symbols. Flow remains its setpoint: cyan drop and white text running, gray paused. RPM is measured while running and setpoint while paused. Red fault notices occupy the spare Z row.

The vertical tip-error gauge retains ten received samples. Latest is yellow; older ticks fade by a factor of 0.60 per newer sample, with overlapping history brightening. Labels: 0, ±0.1, ±1, ±10 degrees. Unlabeled minor ticks: ±0.05, ±0.5, ±5. The inner ±0.1 region is linear, spanning 42 pixels; outer regions are logarithmic. End arrows indicate overflow. The compact bottom label is ΔΘ; only the main tip value carries a degree symbol.

## Base → display records

Existing records are unchanged. New newline-delimited records:

```text
@CHEAT,nominal_index,total_cheat,temporary,target_index
@HUDFAULT,mask
@TIERCOMMENT,tier,text
```

Index values use the current wheel's units; `temporary` is 0/1. The fault mask is encoder stale/fault=1, index motion fault=2, lap fault=4, Z stale=8. These records describe state, not PC motion commands.

Tier comments come from GemCAD ASC `G` cutting instructions (not an `n G` tier name). They are retained per tier, up to 96 characters, and sent after the selected JOB. The graphical header shows one abbreviated line; tiers without comments leave it blank. Reload an already loaded gem after updating to populate this metadata.

## Bench verification after uploading

After a base-only restart, reporting a non-Classic mode now restores the saved SD design even if the display retains its mesh. Previously only a fresh mesh request triggered restoration, allowing built-in facet IDs to address a retained loaded model (Princess showed 9..24 of 48). Built-in JOB/navigation is suppressed while restoration is pending or failed; unrelated controls remain available. Test with the display left powered during a base reset, then cycle all 48 Princess girdle facets with keys 12/13.

Check crown/pavilion tier changes in Static, fixed side rear shading, and the smallest/longest loaded gems. Check temporary cheat clears on facet change; H applies only to that side. Verify nominal index stays fixed while corrected target/error changes. Verify lock dots, step changes, flow pause colors, and gauge history. Syntax/regression checks cannot substitute for this TFT and motion-hardware check.

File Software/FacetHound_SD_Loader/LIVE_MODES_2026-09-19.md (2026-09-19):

# Live modes and Classic tier

Upload baseChassisModule and displayModule_v6_gem. No mast or keyboard changes.

All display mode changes now persist without restarting the display. View
sprites are released when switching rendering families; geometry and its RAM
cache stay resident. A Classic-only cold boot still skips model loading. Its
first switch into a tier-aware view requests geometry if none is resident.

Classic tier's index counter and previous/next values use only the selected
tier, sorted by machine index. Tier keys retain list position when possible;
facet keys wrap within that tier. The named tier selector sits below tip;
signed tip error is on its right, styled like the index error. File names for
tiers take precedence over inferred C/P/G/Table-style labels. No force bar.

Tier-aware mode switches preserve the selected facet instead of selecting a
different tier with the same index. Plain Classic remains a deduplicated index
list independent of tiers.

Validation: Arduino syntax checks and Python geometry/list regressions. Actual
display layout, memory headroom for large models, and live transitions require
hardware testing. No motor parameters changed in this update.

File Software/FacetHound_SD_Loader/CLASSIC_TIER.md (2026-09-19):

# Classic and Classic tier

Upload matching base and display sources. Settings → Display mode now includes
**Classic tier** (`MODE CLASSIC_TIER` over the console). Original Classic remains
the fast machine-status startup without model loading.

- With a loaded gem, plain Classic rebuilds the mark list as sorted unique
  machine index values across all tiers (including the existing pavilion
  half-turn conversion). Facet keys traverse that list; tier keys are ignored.
- Classic tier retains all cut/tier identities and uses the loaded design, or
  the compiled default gem when none is loaded. Tier keys select tiers; index
  keys select facets within a tier. It loads design metadata/mesh like the other
  tier-aware modes, rather than pretending the plain Classic list has tiers.
- The force-bar area becomes `previous tier < current / total > next tier`.
  Below it are target tip angle and signed actual-minus-target error, in degrees.
  Anonymous tiers use `T<number>`; available source names label the neighbors.
- Mode-list reconstruction preserves the current motor target and lock state.
  Ordinary motion fault protection and explicit Home retry remain unchanged.
- Settings configuration snapshots are painted once at END, not once per value.
- Dynamic rendering targets a 20 ms frame interval (up to 50 fps), skips unchanged
  geometry frames, and limits routine HUD refresh to 10 Hz. Actual frame rate
  depends on mesh complexity/SPI time; no clock overclock or baud change is made.

Validation: Arduino-header syntax checks and source-design regression tests.
Hardware frame-rate and UI-layout acceptance are still required.

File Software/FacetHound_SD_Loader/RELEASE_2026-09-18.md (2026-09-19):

# Integration release — 2026-09-18

## Display hotfix after source freeze

Reflash display only: the splash animation is confined to rows 0–369, above the
receiving strip at 382–451; title and gem move upward. The loading sprite is freed
before main-view allocation. Mode initialization forces a HUD redraw and retries
failed sprite allocation instead of leaving Static numbers blank. Syntax checked;
on-device visual acceptance remains required. The original source tag is unchanged.

Source tag: `integration-2026-09-18`. Base/display build marker:
`INTEGRATION-RELEASE-20260918`. This freezes source, not hardware certification.

Source release on `repo_cleanup`; upload with Arduino IDE as documented in
FLASHING.md. Use the base and display sources from the same revision. Mast and
usbToUART firmware are unchanged by this release. No UF2 artifacts were built.

## Final behavior

- Classic boots directly to machine status: no splash/model-loading dependency.
  The base restores geometry only when a graphical display requests it.
- Dynamic ↔ Static changes mode in place, keeping the active mesh and RAM cache.
  There is no reboot, geometry reconstruction or mesh transfer for that switch.
  Transitions involving Classic retain restart behavior to free incompatible
  screen buffers; entering Classic still skips the loading/splash sequence.
- Receiving-model progress is drawn off-screen and pushed as one sprite, capped
  at 10 updates/second outside the animated splash. The temporary sprite is freed
  before normal rendering.
- Motor control is unchanged from the user's working trial.

## Release checks and limitations

Changed translation units: Arduino-header syntax checks. Geometry regressions:
four source designs, culet reconstruction, Backgammon bounds/girdle visibility.
No full build, physical upload, timing benchmark, or manufacturing approval.

Hardware cable schematic: `Hardware/pcb/integration/ModuleInterconnect.sch` and
its companion INTERCONNECT.md. Existing PCB routing and historical ZIPs are
untouched. Native Eagle visual/ERC review is still needed before fabrication.

Acceptance trial: power on in Classic; switch Dynamic→Static→Dynamic without a
reset/splash; load a model and watch the receiving bar; verify all module cable
pad numbers against the new interconnect with power disconnected.

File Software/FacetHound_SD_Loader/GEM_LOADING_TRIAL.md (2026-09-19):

# Gem loading and index seek trial — 2026-09-18

For final Classic startup, mode switching and release behavior, see
RELEASE_2026-09-18.md; it supersedes the earlier trial notes below.

## Settling/start follow-up

- Small index crossings now halve correction gain, speed and acceleration, with
  a 100 ms feedback-settling pause between legs. Three crossings no longer latch
  OVERSHOOT. Large crossings (>2 units), movement away, invalid feedback and a
  30-second failure to converge still stop the seek. Settled means within the
  existing tolerance on fresh samples, followed by energized, non-servo hold.
- Each lap start now requires a fresh disabled/brake acknowledgment, at least
  500 ms disabled, and fresh stopped-speed/fault-clear replies. Logs distinguish
  START_REQUEST, START_READY and START_NOT_READY. A running drive fault still
  pauses; there is no automatic repeated stall retry or current-limit increase.
- Geometry is built in RAM without saving an automatic cache. Existing valid
  PC-prebuilt caches are accepted. Only the tiny last-selected filename is saved.
- The initial splash continues rotating during loading. The separate text-only
  loading card uses the splash's smooth title font and cyan/magenta treatment.

## Display-cache and orientation follow-up

The base fingerprints mesh geometry and facet metadata before transfer and sends
`@MESHCACHE,<64-bit-hex-id>`. The display responds with `@MESHACK,CACHE_HIT` or
`@MESHACK,CACHE_MISS`. A hit swaps in the resident model and skips all mesh rows;
USB reports `@GEM,DISPLAY_CACHE_HIT`. A miss (or timeout) uses the normal transfer.
The display holds up to two previous small models in addition to the active one,
with a combined 24 KiB cache budget and eviction to leave room for an incoming
model and UI. Oversized models are not retained; all entries disappear at reset.
This is RAM only, not display flash or another SD write.

Crown facets add an interpolated 180-degree screen roll: the selected normal
still faces the viewer, but the culet is down. Static T/B visibility now uses
supporting face normals, not whether an edge lies above z=0. Vertical girdle
boundaries appear in both cap views. Regression checks reconstruct Backgammon,
verify all four projected bounds, and verify its 44 girdle edges in T and B.

Upload both `baseChassisModule` and `displayModule_v6_gem`. No mast or keyboard
firmware change is required. Both report build `DISPLAY-CACHE-20260918`.

## Operator checks

1. Load an ASC through settings. Loading releases index/Z; a running lap is
   paused and its brake command/low speed must be confirmed before reading SD.
2. The loading screen shows stage text and a model-transfer progress bar. Each
   mesh record is acknowledged, with bounded record retries and whole-transfer
   retries. A transfer failure does not substitute the built-in geometry.
3. Press Home (K / key 14) to engage index and seek the selected mark. This is an
   explicit operator retry of a latched index fault; invalid/stale feedback still
   blocks motion. Facet changes seek automatically while locked. Unlocked facet
   changes only change selection. At rest the driver holds without idle hunting.
4. At the target, the selected face should face the viewer. Actual index drives
   yaw, selected tier sets inclination; live tip does not rotate the model.
5. Index/Z HUD indicators are grey outlines when unlocked, colored disks when
   locked. Long names wrap in the left half; classic counters fit three digits.
6. Settings → Loaded gem info shows two pages of source/geometry metadata. Turn
   the wheel to switch pages. The SD list shows title plus filename; unrecognized
   headers have a `null` title, not a fabricated design name.
7. Restart with the card inserted: `/facetHound.last` identifies the saved ASC.
   Splash/loading remains visible while restoring instead of showing a demo gem
   paired with the saved marks. A missing remembered file reports an error.

## Geometry/cache changes

Face orientation is derived from mesh edge geometry, including each source's
meridian and index convention. Static panels independently fit their projected
bounds. GemCad zero-angle culets with negative distance now clip the pavilion,
not the crown. Firmware and PC converter use cache version 2; version 1 caches
are rebuilt from the ASC automatically. Keep the ASC files; no card reformat.

Run `tools/test_gem_regressions.py` directly or from Spyder (numpy required).
It checks face-to-viewer transforms for pc04188, pc42011, pc01028c and pc01043,
and reconstructs the Dodecahedron to check its full vertical extent.

## Diagnostics and limitations

`@INDEX,SEEK` reports target, actual and UNLOCKED / WAIT_FEEDBACK /
FAULT_LATCHED / SEEKING. A new facet does not automatically clear a motion fault;
Home explicitly retries. Stop and investigate recurring moving-away faults.

BLD fault 0x01 is a locked-rotor report. Firmware now pauses on that fault instead
of repeatedly driving the stalled motor. The supplied failed-direction trace had
startup_boost=0 and a 560 RPM command; it does not establish that the kick caused
the stall. This patch does not claim to fix Hall/phase commutation or raise current.

Validation: changed firmware translation units pass Arduino-header syntax checks;
no full firmware build, upload, or physical-motion validation was performed.

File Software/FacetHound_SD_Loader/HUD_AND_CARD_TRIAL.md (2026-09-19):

# HUD, exact selection and card trial

## RPM factor-of-two correction

Base-only update. Captured reply 01-03-02-25-00-A2-D4 carries little-endian
speed raw=37. The 8018 manual specifies raw*20 divided by MOTOR POLES.
The four-pole motor therefore reports 185 RPM, not the previous 370. The
control word still uses 2 POLE PAIRS. Speed commands, 200 RPM cap, wiring,
ramp and current settings are unchanged. Both asynchronous telemetry and
the demo library now use the same conversion. @MOTOR adds rpm_divisor_poles=4.
At the same physical operating point, the HUD should show about 185..190
running and 200 paused (setpoint). Below-speed stalling remains a separate
operating issue; this display correction does not change motor torque/speed.
Source: https://ae01.alicdn.com/kf/Sdb18dfe1fd7741f7bf6f43a54702a5abB.pdf
Earlier notes describing raw*20/pole-pairs scaling are superseded here.

## Locked-only model motion and averaging follow-up

Upload display and mast for this follow-up (base still needs the preceding
3926f00 fractional-index conversion and 0.009 tolerance).
Unlocked: exact facet highlight/name changes, but rendered orientation freezes,
including an interpolation already in progress. Locked: actual index controls
rotation and selected tier controls tilt. Physical tip does not drive the model.
The first frame initializes once even if unlocked. Machine-wheel units are
converted to mesh index units before rendering.

Index averaging was NOT removed: it still uses 16 circular samples; tip uses 8.
However the final index average was rounded to one native encoder count.
It now stays floating point and @twist prints five decimal places in the same
4096-units/revolution scale. This preserves fractional sample estimates; it
does not prove sub-LSB accuracy in the absence of noise/dither and calibration.

Do not erase the populated SD card. Previous failures are at the command/read
layer, not evidence that formatting is needed. Back up before any later format.

Lap phase-matching trial: leave all Hall wires and drive settings fixed. Label
the three MOTOR-side phase leads A/B/C by their current MA/MB/MC connections,
not by assumed colors. Record baseline and test distinct MA/MB/MC assignments:
ABC, ACB, BAC, BCA, CAB, CBA. Disconnect 24 V and wait for the drive supply to
discharge before EVERY connector change; never hot-swap motor leads. Secure
the motor, preferably uncoupled from the lap, insulate all bullet connectors,
keep hands clear and have STOP/power isolation immediately available. Use the
same modest setpoint/direction each time; abort immediately on shudder, stall,
unexpected speed, fault or excessive current. Do not dwell stalled or raise
current limits. A candidate must start smoothly and then work in the opposite
commanded direction after a complete stop; rotation alone is not proof of a
correct match (incorrect timing can run with poor torque/high current). If no
combination is smooth, stop permutations and verify Hall state sequence and
Hall supply under load, controller outputs and mechanical load. Do not cycle
through Hall power-wire arrangements. Near-zero winding readings on a normal
meter can reflect low winding resistance; OL/open is a different failure.
Reference: https://e2e.ti.com/support/motor-drivers-group/motor-drivers/f/motor-drivers-forum/1102147/mct8316z-motor-lock-error-detected-everytime

## Full-resolution index / dedicated-SPI trial

Upload mast, base and display together for this trial. Mast now retains all
14 AMT232B position bits. @twist keeps its legacy 4096 units/revolution, but
uses fractional quarter counts (e.g. 245.25). Base converts the floating-point
value before truncating the legacy integer diagnostic/calibration field.
No bit-bang timing, pin, MODE wiring or parity changes. At wheel 96 the
measurement increment is 96/16384 = 0.005859375, rather than 0.0234375.
Stop tolerance is 0.009 index units, with no automatic coarse-count enlargement.
Settled holding remains passive: no feedback pulses until a fresh seek.
This is resolution, not a claim of calibrated mechanical accuracy. Larger
wheel resolutions may exceed this tolerance's quantization requirement.

Display drains up to 2048 bytes/128 lines per loop instead of 320/12, preserving
wire order, before the next redraw. A received changed selection emits
@JOBACK,tier,facet; base TRACE ON exposes it. This lets a missed key be separated
from delayed display receipt. Model rotation still follows actual index until
the user chooses preview-versus-live behavior; physical tip never drives pose.

Installed Arduino-Pico 5.6.0 SdFat error 0C is CMD18; data 04 is illegal command.
Sector 0 already read using that library, so this is not proof of a bad format.
Use the existing SDFS implementation with a small begin/end override selecting
DEDICATED_SPI for the card-only bus and actually closing SdFat on end. All
existing SD/File/cache APIs remain intact; no installed library files change.
Mount attempts print @SD_MOUNT with library error/data. This is a trial for
read/stop/restart reliability, not yet validated on hardware. No formatting.

BLD readback C02/1414/AA0F/C800 means brake, two pole pairs, 2 s ramps,
sensored mode, and 200 RPM setpoint. Do not increase current. With power off,
disconnect motor phase leads and compare the three pairwise winding resistances;
all should be similar, with none open. Account for test-lead resistance. Keep
phase leads isolated for powered Hall-only testing. Verify Hall supply at the
motor, then hand-turn and check all three Hall outputs switch. Valid switching
does not alone prove phase/Hall alignment. Do not infer wire mapping from the
ambiguous photos or randomly swap the Hall power leads.

## Settled hold / keyboard / SD / lap integration follow-up

Upload base and display; mast and keyboard unchanged. Index now latches settled
on the first in-tolerance feedback sample and stops queued pulses. Holding
current stays enabled, but encoder drift does NOT restart movement. Only a
new target, explicit seek, or re-engagement re-arms it. Final approach speed
is capped at 300 pulses/s per remaining index unit (100 minimum, existing
1800 maximum). Overshoot/wrong-direction/invalid-feedback protections remain.
Z has no position feedback correction loop: it holds after explicit jog pulses.
Physical vibration with no new jog would need electrical/driver investigation.

Flash autosave waits for 1.5 seconds without keyboard actions and no pending
index/Z motion. Facet/tier changes repaint model and HUD without waiting for
their normal frame intervals; selection still uses exact JOB identities.

SD PROBE additionally uses the installed SdFat library's SdInfo approach:
cardBegin, sector-0 read, volumeBegin. @SD_FS prints error/data codes and,
if readable, sector signature and partition types. No formatting/file writes.
CMD8=01/000001AA, ACMD41=00 and OCR=C0FF8000 indicate successful SDHC/SDXC
initialization for that transaction, not proof of reliable sector reads.
Use STOP, SD PROBE; paste all @SD_FS records. Card size and filesystem as
reported by the PC are also useful; do not reformat existing data for this test.

Lap comparison used origin/uiReno's BLD510B_Demo_copy_20260918125840 sketch.
It sets register 8003 to 1414 (2 seconds each) before speed/enable; integration
now restores that acknowledged configuration. Existing current limit, sensored
mode and pole pairs are not altered. Pause commands take precedence over ramp
configuration. MOTOR DEMOPROBE now also reads 8000..8005 via that same library
and prints @BLD_CONFIG (control, ramp, current_mode, speed_wire).

Lap trial: keep mechanism clear, stop other motion, send STOP and RPM 200.
Then send MOTOR CW, watching the shaft; stop immediately with STOP if it
shudders or stalls. Do not leave it energized stalled. If it turns smoothly,
stop fully before trying MOTOR CCW. Do not queue CW and STOP back-to-back in
one paste as that would not exercise startup. After stopping, MOTOR DEMOPROBE
reports drive configuration. The manual describes approximately 150 RPM minimum;
the proven demo used 500/1500 forward and 800 reverse, not the recent 12..92.
This trial does not assert that low speed is the sole cause. If still shuddering,
check @BLD_CONFIG mode byte against documented 0F sensored (10 sensorless)
and measure each Hall signal toggling with hand rotation before phase swaps.
Source: https://ae01.alicdn.com/kf/Sdb18dfe1fd7741f7bf6f43a54702a5abB.pdf

Source/regression checks only; no Arduino build or physical validation claimed.

RPM follow-up: hand-spin reports of 51200 and 66560 match the speed-register
byte-order error exactly (wire 14 00 / 1A 00). Register 0x8018 is now decoded
low-byte-first, producing 200 / 260 RPM under the existing 20/pole-pairs scale.
Raw diagnostic fields remain unchanged. Status/fault register byte order is NOT
swapped. Absolute scale still needs a tachometer check; motor shudder is not
fixed merely by correcting the display reading.

Upload baseChassisModule and displayModule_v6_gem. Mast is unchanged.

- Static/dynamic highlight uses the JOB tier/facet identity, not the nearest
  angle/index. Unknown identity has no highlight. All 128 built-in poses/IDs
  were compared between base and display and match.
- Dynamic rotation follows live index with short shortest-path easing (65 ms
  time constant, approximately 95% complete in 195 ms). Physical tip
  only affects HUD values/errors; model inclination comes from the selected tier.
- Both HUDs show index and Z LOCK/FREE state from existing TLK/ZLK telemetry.
  These are commanded engagement states, not driver electrical feedback.
- Flow always shows its setpoint. Running: cyan droplet and white text;
  paused: grey droplet and text. State is flow_dir 0/2 running, 1/3 paused,
  regardless of setpoint magnitude. RPM text/arrow are white running, grey paused.
- Animated title card runs every restart, with a 300 ms fade to black at the end.
  Credit footer remains a separate sprite and only changes during the fade.
- Tier navigation preserves ordinal position in the source tier list, with
  the first entry as fallback if the new tier is too short. No angle/distance
  matching is used. This applies to SD-loaded and built-in designs. Existing next/previous
  facet commands are unchanged. No motion limits/acceleration were increased.

## SD electrical test

The eBay listing offers multiple module variants. Its title alone and 3.3 V
across the module input do not establish the card's actual supply. Identify the
module/regulator before changing its supply; never apply 5 V to a bare card or
Pico signal. No automatic formatting or erasing is performed.

The supplied reader photo resolves the pinout: 3V3, CS, MOSI, CLK, MISO, GND.
For the straight-through v9 header this means CS10, MOSI11, CLK12, MISO13.
Firmware previously had MOSI/CLK reversed; now corrected. Keep 3.3 V supply.
SD PROBE is an SPI command, not a card-detect GPIO test.

Display now consumes the existing @A actual-index record directly. Target and
error records can no longer mix across frames to produce a false pose. Until A
arrives the model holds its index; physical TIP cannot set model orientation.
Base sends A in the normal telemetry cycle and display-test mode. Other PC
proxies should send @A,<actual-index> along with T/E. Selected tier sets inclination.
Axis-gutter indicators are filled dots only: grey unlocked, axis color locked.
HUD uses its own version counter so a run/pause change remains pending until
painted. Flow color depends exclusively on FLD (0/2 cyan, 1/3 grey), not FLW.
On a flow-state change the display emits @UIFLOW,dir=...,running=... on both
serial ports; base TRACE ON exposes it. Build banner: SPLASH-FADE-HUD3.

## Known lap motor and index polarity test

57BLR70-24-02 is 4-pole = 2 pole pairs, already configured correctly. Manufacturer
connection table: U/V/W yellow/green/blue, Hall A/B/C yellow/green/blue,
Hall +5V red and GND black. Map motor U/V/W to BLD MA/MB/MC and Hall A/B/C to
HA/HB/HC. A white lead differs from this drawing; identify it rather than guessing.
Source: https://www.omc-stepperonline.com/24v-3500rpm-0-47nm-172w-10-4a-57x69mm-brushless-dc-motor-57blr70-24-02

The current speed command is shaft RPM, not a fraction of a coil or a percentage.
No changes to current limits, pole pairs, Hall mode or RPM scaling made here.

For index direction leave the mechanism clear, switch tip-servo off, stop lap
and pump, unlock both axes and wait for valid encoders. Send INDEX PROBE. This
commands only 128 positive pulses (travel depends on actual microstep setup),
prints measured start/end/delta and a suggested sign, then releases the motor.
It is nonblocking, cancellable with STOP, times out at 2.5 s, and does not
automatically apply the suggested sign or start a target seek. Do not operate
other axis controls during this test. Send its result before another sign flip.

```text
STOP
SD PROBE
SD RETRY
SD LIST
```

CMD0 response 0x01 means the card answered in SPI idle state. 0xFF means no
answer to this test; investigate card power/CS/clock/MOSI/MISO and socket/card.
Other responses need interpretation rather than being called a filesystem fault.
If CMD0 works but mounting fails, also check card filesystem/partition support.
Do not format a card containing files to test this without backing it up.
PROBE resets protocol state, so RETRY is required afterward. Once mounted:

```text
GEM LOAD 0
MODE DYNAMIC
```

Use the desired file's index from SD LIST. Loading remains blocked during motion.

### Staged SD initialization trial

Repeated CMD0=01 with an inserted card and FF with no card establishes that
the card can answer, but intermittent 7F still means communication is not yet
reliable. MISSING is a generic mount failure, not a card-detect switch reading.
SD PROBE now follows a successful CMD0 with CMD8 (expected R1=1, R7=000001AA
for a v2 card), CMD55/ACMD41 (expected ready R1=0), and CMD58 (expected R1=0,
OCR printed). Ready polling is capped at one second. A CMD8 illegal-command
response takes the older SD initialization path. No sector writes or formatting.
SD RETRY transfer ceiling is reduced from 1 MHz to 250 kHz for this trial;
the underlying library still controls its own initialization clock.
If all protocol stages succeed but mounting fails, check filesystem/card
support and sector-read reliability rather than assuming an open wire.

Hall wiring photo correction: user confirmed red is in the Hall +5V terminal.
Do not confuse the adjacent logic-bank GND with the Hall-bank terminals.
The photos do not reliably establish all individual lead-to-terminal mappings;
do not recommend wire swaps based on those ambiguous images.

## Lap shudder / implausible RPM

Keep stopped while checking motor phase and Hall wiring against the actual
motor documentation. A valid Modbus reply or fault=0 does not prove commutation
is correct. Do not raise current or bypass Hall protection. The posted snapshot
is paused with zero RPM, so it does not show the implausible running value.

MOTOR STATUS includes speed_raw (wire big-endian interpretation of register
0x8018), speed_raw_swapped (the little-endian value used for RPM), and pole_pairs.
Current limits, motor mode and pole-pair configuration are unchanged.

## Index settling trial

Circular error now normalizes any number of whole turns, not just one. For the
reported target 3 / actual 1.9922 on a 96 wheel, error is +1.0078, not a wrap
ambiguity. The old controller latched on any target crossing beyond one count.
Correction gain is restored to 0.2. A crossing up to 2 index units may settle
for 100 ms with coils held, then correct; at most three such corrections are
allowed per target. Larger crossings/repeated hunting still fault. Wrong-way
and stale-encoder protections remain enabled. Fault telemetry preserves error.
Do not change motor polarity blindly: use the guarded INDEX PROBE above.

Source/diff and built-in identity checks performed; no IDE compile, hardware
upload, panel screenshot verification or physical card access claimed.

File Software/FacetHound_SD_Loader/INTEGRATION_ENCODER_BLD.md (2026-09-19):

# Encoder startup, powered hold, and BLD isolation trial

## Latest bench results and trial

- Removing MODE conductors fixed encoder cold start. Leave encoder MODE pin 5
  permanently unconnected; retain the other five conductors.
- Replacing the RS485 adapter produced valid BLD reads/writes without CRC errors.
  Fault 0x04 is Hall value abnormal, NOT current limiting (overcurrent is 0x02).
  Verify motor Hall +5V/GND and HA/HB/HC against motor documentation, with power
  off for rewiring. Do not raise current limits or switch to sensorless blindly.
- Provisional tip down zero is 82832; horizontal sample 115896 yields 90.813 deg.
  The old default 47850 migrates; custom stored zeros remain. Range wraps at
  -90/270, outside down=0, horizontal=90, up=180. Table adapter subtracts 45.
- Paused BLD control now matches the original library's 0x0C brake word instead
  of 0x0D (enable+brake). Status faults refresh every fourth telemetry poll.
  The legacy DEMOPROBE `run` field is the status register's low byte; the manual
  calls this byte reserved, so do not interpret 21 as a running speed/state.

BLD source: https://ae01.alicdn.com/kf/Sdb18dfe1fd7741f7bf6f43a54702a5abB.pdf

SD uses a conservative 1 MHz SPI transfer rate for this trial. From base USB:

```text
STOP
SD RETRY
SD LIST
GEM LOAD 0
MODE DYNAMIC
```

Replace 0 with the desired file index in SD LIST. If RETRY is not READY, stop
there: firmware cannot load an unmounted card. Report that result and card
format/capacity; do not format or erase it. Root-level ASC/FCT sources are listed;
matching FHC caches are loaded automatically, or built/saved when absent. This
trial does not claim SD hardware success before the user's bench test.

Flash baseChassisModule and mastModule for this trial. Display and keyboard
firmware are unchanged. No encoder zero-setting or homing command is sent.

## Encoder cold start

The mast releases GPIO26/27 (MODE translator inputs) and all DATA pulls before
reading. CS output latches are set high before output enable. The existing
500 ms startup wait and legacy clock edges remain. Bad checksum transactions
are retried up to three times; bad data never becomes a position measurement.

The AMT23 datasheet requires MODE to be left open in normal operation and
the shaft stationary during its 200 ms startup. Releasing GPIO26/27 does NOT
disconnect the board's TXB0108 from MODE. If a cold power cycle still produces
encoder_fault=3 until reseating, with power OFF reversibly isolate the MODE
conductor on both encoder cables, leaving the other five connections intact.
IMPORTANT: MODE is pin 5 at the AMT232 encoder, but pin 2 at the v8 mast PCB
J5/J2 connectors. These numbering systems are reversed; do not confuse them.
Confirm continuity before removing a contact: J5.2 -> U2 B7 -> A7 -> GP26;
J2.2 -> U2 B8 -> A8 -> GP27 (the translator is not a direct continuity path).
Remove/insulate a connector contact to test first; do not cut traces yet.
Pin 2 AT THE ENCODER is DATA and must remain connected. Do not hot-plug.
Test a full cold start with shafts stationary, before engaging motor locks.

Reference: https://www.sameskydevices.com/product/resource/amt23.pdf

## Motion and holding

Z now gets software enable before its configuration UART is released, just as
index does. Both use active-low hardware EN and NORMAL standstill mode for
powered holding when locked; do not physically short motor coils.

A rejected index sample stops pending pulses without releasing lock. A fresh
valid sample permits movement again unless a sustained feedback, moving-away,
or overshoot fault has latched. Those faults keep powered hold, print @FAULT,
and require unlocking then locking again. Fix the cause before re-arming.
Explicit unlock/emergency stop still releases the driver. The target tolerance
is at least one transmitted index count (about 0.02344 on a 96 wheel), not an
unreachable fraction of one count. Settled position is checked again for drift.

## BLD: isolate the actual GP8/GP9 UART path

1. Stop lap, pump and both axes. Power OFF before touching connectors.
2. Disconnect the TTL-to-RS485 adapter from base TX/RX. Jumper base GP8 (TX)
   to GP9 (RX), preferably at the PCB adapter connector to include its traces.
   Do NOT jumper RS485 A/B, power pins, or two connected output drivers.
3. Power the base; leave index/Z unlocked and lap paused. Send `MOTOR LOOPBACK`.
4. Expect `@BLD_LOOPBACK,match=1,rx_bytes=8,hex=...`.
   - No bytes: test the same jumper directly at GP8/GP9. A direct pass but
     connector failure isolates the PCB/connector path.
   - Bytes but mismatch: investigate UART timing/clock and signal integrity.
   - Exact match at the connector: base UART path works. Power OFF, remove
     jumper, reconnect adapter; then `MOTOR DEMOPROBE` tests the downstream
     path with the exact uiReno library. Loopback alone does not test RS485.

LOOPBACK blocks for approximately 110 ms, only on explicit command. It sends a
read-only Modbus status request, not a speed, run, or address-change command.
It does not interpret an echo as proof that the BLD responded. This test does
not claim the silent drive is fixed; it produces a discriminating next result.

SD remains reported missing; no SD or pin-assignment changes are part of this
trial. These edits were source-reviewed, not hardware-verified or IDE-compiled.

## Index seek/hold and loopback follow-up

Index lock means seek the selected target then maintain holding torque; it
does not mean simply stop wherever the axis happens to be. With menu closed,
L (`KEY 15`) toggles it. A state with twist_lock=0 explicitly disables seeking.
If tip-servo is enabled it releases index above 120 degrees, recaptures below
105 degrees. For a manual index test turn Servo OFF in Settings. New STATUS
fields twist_ready, index_fault_latched, tip_servo distinguish the motion gates.
Runtime keyboard/servo paths now use hardware EN only, never the released
one-time TMC configuration UART. Sustained faults still require unlock/relock.

After a passing loopback remove the GP8/GP9 jumper with power off, reconnect
the adapter, then power up and run MOTOR DEMOPROBE. An echoed 8-byte request
01-03-80-1B-00-01-DD-CD is NOT a drive response. The normal parser expects a
7-byte response, so loopback requests appearing there produce CRC failures;
this alone does not indicate wrong CRC generation or a BLD fault.

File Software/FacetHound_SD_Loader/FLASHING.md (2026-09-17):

# Flashing the complete electronics set

These four sketches are the matching current source set. Build them from this
folder; older UF2 artifacts elsewhere in the repository predate the latest
integration changes.

| Controller | Sketch | Board target | Special settings |
|---|---|---|---|
| Base | `baseChassisModule/baseChassisModule.ino` | Raspberry Pi Pico 2 | Arduino-Pico 5.6.0, normal board defaults |
| Mast | `mastModule/mastModule.ino` | Waveshare RP2040 Zero | `RunningAverage` library |
| Display | `displayModule_v6_gem/displayModule_v6_gem.ino` | Waveshare RP2040 Zero | Install `PioEncoder`; force `User_Setup_HX8357D_RP2040.h` into TFT_eSPI |
| Keyboard USB host | `usbToUART/usbToUART.ino` | Waveshare RP2040 Zero | 240 MHz, Optimize `-O`, Adafruit TinyUSB stack |

## Arduino IDE checklist

1. Install Earle Philhower's Arduino-Pico core version 5.6.0.
2. Install `RunningAverage`, `TFT_eSPI`, `PioEncoder`, and
   `Adafruit TinyUSB Library` as required by the sketches above.
3. For the display only, configure TFT_eSPI with
   `displayModule_v6_gem/User_Setup_HX8357D_RP2040.h` before compiling.
4. Select the board and options from the table for each sketch. In particular,
   restore normal defaults after flashing the keyboard bridge so its 240 MHz
   overclock is not accidentally applied to another module.
5. Flash and smoke-test each controller by itself before connecting UARTs or
   motor power. Then follow `INTEGRATION_TEST.md`.

## Verified builds

| Controller | Flash | Static RAM |
|---|---:|---:|
| Base | Upload from Arduino IDE; current diagnostic build not re-measured | - |
| Mast | 61,172 bytes | 9,672 bytes |
| Display | 393,024 bytes | 29,232 bytes |
| Keyboard USB host | 90,404 bytes | 33,008 bytes |

## Inter-controller links

All logic UARTs are 3.3 V TTL and require a shared ground.

| Link | Wiring | Baud |
|---|---|---:|
| Keyboard bridge to base | bridge TX0 -> base RX6; bridge RX1 <- base TX7 | 115200 |
| Mast to base | mast TX8 -> base RX2; mast RX9 <- base TX3 | 115200 |
| Display to base | display TX8 -> base RX4; display RX9 <- base TX5 | 460800 |

### V8 connector pin order

The GPIO mapping above describes signal direction.  The physical connector pin
order is equally important:

| Connector | Pin 1 | Pin 2 | Pin 3 | Pin 4 |
|---|---|---|---|---|
| Base `DISPLAY` | supply | base RX4 | base TX5 | GND |
| Display-board UART end | GND | display RX9 | display TX8 | supply |
| Base `MAST` | supply | base RX2 | base TX3 | GND |
| Mast-board UART end | GND | mast RX9 | mast TX8 | supply |
| Base `KEYS` | supply | base RX6 | base TX7 | GND |
| USB-host board | supply | bridge TX0 | bridge RX1 | GND |

Therefore the display and mast cables reverse all four conductors
(`1->4, 2->3, 3->2, 4->1`).  The keyboard USB-host cable is straight through
(`1->1, 2->2, 3->3, 4->4`).  Verify connector pin numbers with continuity;
do not infer them from wire color or from which side of a housing is visible.

Do not join the modules through a PCB with a suspected rail short. Validate the
PCB rails first, then add these links one at a time as described in the
integration guide.

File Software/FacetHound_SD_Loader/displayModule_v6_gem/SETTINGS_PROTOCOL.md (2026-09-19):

# Settings/menu protocol

The display renders the menu. The base owns machine settings, persistent mark
points, and the physical keyboard. Messages are newline-delimited ASCII on the
existing 460800-baud display UART. USB Serial accepts the same commands for
proxy testing.

## Physical controls

The base suppresses normal motor actions while the menu is open.

- Top-left/former wheel-index key: open menu; back in menus; coarser tier while
  editing a number.
- Main twist wheel left/right: menu up/down.
- Main twist wheel click: select or save.
- Former servo key: finer numeric-edit tier.
- Former cheat key: delete the selected mark point.

The constants are grouped near the top of `baseChassisModule.ino` if a keypad's
HID assignments need to be changed.

## Menu control

```text
base -> display: @MENU,TOGGLE
display -> base: @MENU,OPEN
base -> display: @MENUKEY,UP
base -> display: @MENUKEY,DOWN
base -> display: @MENUKEY,SELECT
base -> display: @MENUKEY,BACK
base -> display: @MENUKEY,FINER
base -> display: @MENUKEY,DELETE
display -> base: @MENU,CLOSED
```

The display also accepts `@MENU,?` and replies with its current state. It sends
that state with its one-second heartbeat, allowing the base safety interlock to
self-correct after a dropped packet. `@MENU,1`/`OPEN` and `@MENU,0`/`CLOSE`
remain supported for diagnostics.

`OPEN`/`CLOSE`, `OK`/`ESC`, and an explicit `COARSER` menu key are also
accepted.

## One snapshot on entry

```text
display -> base: @CFGGET,ALL
base -> display: @CFGSYNC,BEGIN
base -> display: @CFG,INDEX_DIRECTION,CW
base -> display: @CFG,TABLE_ADAPTER,OFF
base -> display: @CFG,SERVO_ENABLED,OFF
base -> display: @CFG,WHEEL_INDEX,96.0000
base -> display: @CFG,Z_POLARITY,NORMAL
base -> display: @CFG,FLOW_CONVERSION,0.052000
base -> display: @CFG,INDEX_SPIN_RPM,0.000000
base -> display: @CFG,POSITION_COUNT,16
base -> display: @CFGSYNC,END
```

Machine settings do not stream continuously. Mark-point values are the one
exception: they are fetched in small pages only while the list is visible, so
an arbitrarily long runtime list does not consume a second full copy of RAM on
the display.

```text
display -> base: @CFGGET,POSITIONS,0,8
base -> display: @CFGSYNC,POSITIONS_BEGIN,0,8
base -> display: @CFG,POSITION_0,0.0000
...
base -> display: @CFGSYNC,POSITIONS_END
```

## Writes and actions

```text
@CFGSET,DISPLAY_MODE,CLASSIC
@CFGSET,INDEX_DIRECTION,CW
@CFGSET,TABLE_ADAPTER,ON
@CFGSET,SERVO_ENABLED,ON
@CFGSET,WHEEL_INDEX,96
@CFGSET,Z_POLARITY,REVERSED
@CFGSET,FLOW_CONVERSION,0.052000
@CFGSET,POSITION_12,72.5000

@CFGACTION,RESET_POSITIONS,4
@CFGACTION,ADD_POSITION,0
@CFGACTION,DELETE_POSITION,12
@CFGACTION,LOAD_SD_FILE,0
@CFGACTION,ZERO_ENCODER,INDEX
@CFGACTION,ZERO_ENCODER,TIP
@CFGACTION,ZERO_ENCODER,Z
@CFGACTION,ZERO_ENCODER,ALL
@CFGACTION,INDEX_SPIN_START,-1.25
@CFGACTION,INDEX_SPIN_STOP,0
```

Reset spacing accepts 4, 8, 12, 16, or 32. SD files are fetched in six-name
pages with `@CFGGET,SD_FILES,start,6`; the base reports `SD_STATUS`,
`SD_FILE_COUNT`, and `SD_FILE_n` rows. A successful selection returns
`@CFGACK,LOAD_SD_FILE,title`, followed by periodic
`@JOB,tier,facet,angle,gemcad-distance,index,name` rows. The distance field is
retained as file metadata and is never treated or displayed as machine Z.
Applied writes use
`@CFGACK,id,value`; rejected writes use `@CFGNAK,id,reason`.

When Table Adapter is ON, the base reports:

```text
tipDegrees = calibratedTipDegrees - 45.0
```

Changing index direction safely stops twist correction, changes the encoder
and motor sign convention, and reacquires the current twist position before
allowing a new correction.

Continuous index spin accepts signed 0.01-10 RPM. While running, the display
renews the command every 500 ms; the base hard-stops after 1.5 seconds without
a renewal. Leaving the spin page also sends an explicit stop.

## Runtime gem mesh

After building a loaded ASC/FCT design, the base streams `MESHBEGIN`, sequential
`MESHV` vertices, `MESHE` edges, `MESHP` facet poses/names, and `MESHEND`. Edge
rows contain a compact list of supporting plane ids for facet highlighting.
Each plane row retains the imported name (`C1`, `P1`, `G2`, `T`, etc.) for the
tip-angle HUD. The base waits for `@MESHACK,BEGIN`, then sends one geometry row
per 5 ms without blocking its main loop. The display suspends rendering during
receipt. Transfer is activated only when every declared row arrives in order.
`@MESHACK,READY` closes settings, resets the view pose and redraws the current
mode with the new mesh. A failed transfer shows a reload error instead of
rendering the built-in mesh with the loaded job's points. The base reports
`@GEM,DISPLAY_READY` or `@GEM,DISPLAY_ERROR,...` to USB; `@GEM,LOADED,...`
alone means the base has loaded/built geometry, not that the display has it.
The display requests recovery with `@CFGGET,MESH` at boot. Both base and
display firmware must be updated together for the BEGIN handshake.

Runtime limits are 512 planes, 1,024 vertices, and 2,048 edges.

## Mark-point capacity

The base uses `std::vector<float>` at runtime, so there is no fixed 16-point
logic limit. Capacity is bounded only by available RAM. The included raw-flash
record reserves the final 64 KiB and persists up to 16,320 float positions;
larger runtime lists are valid but cannot be saved by this record format.

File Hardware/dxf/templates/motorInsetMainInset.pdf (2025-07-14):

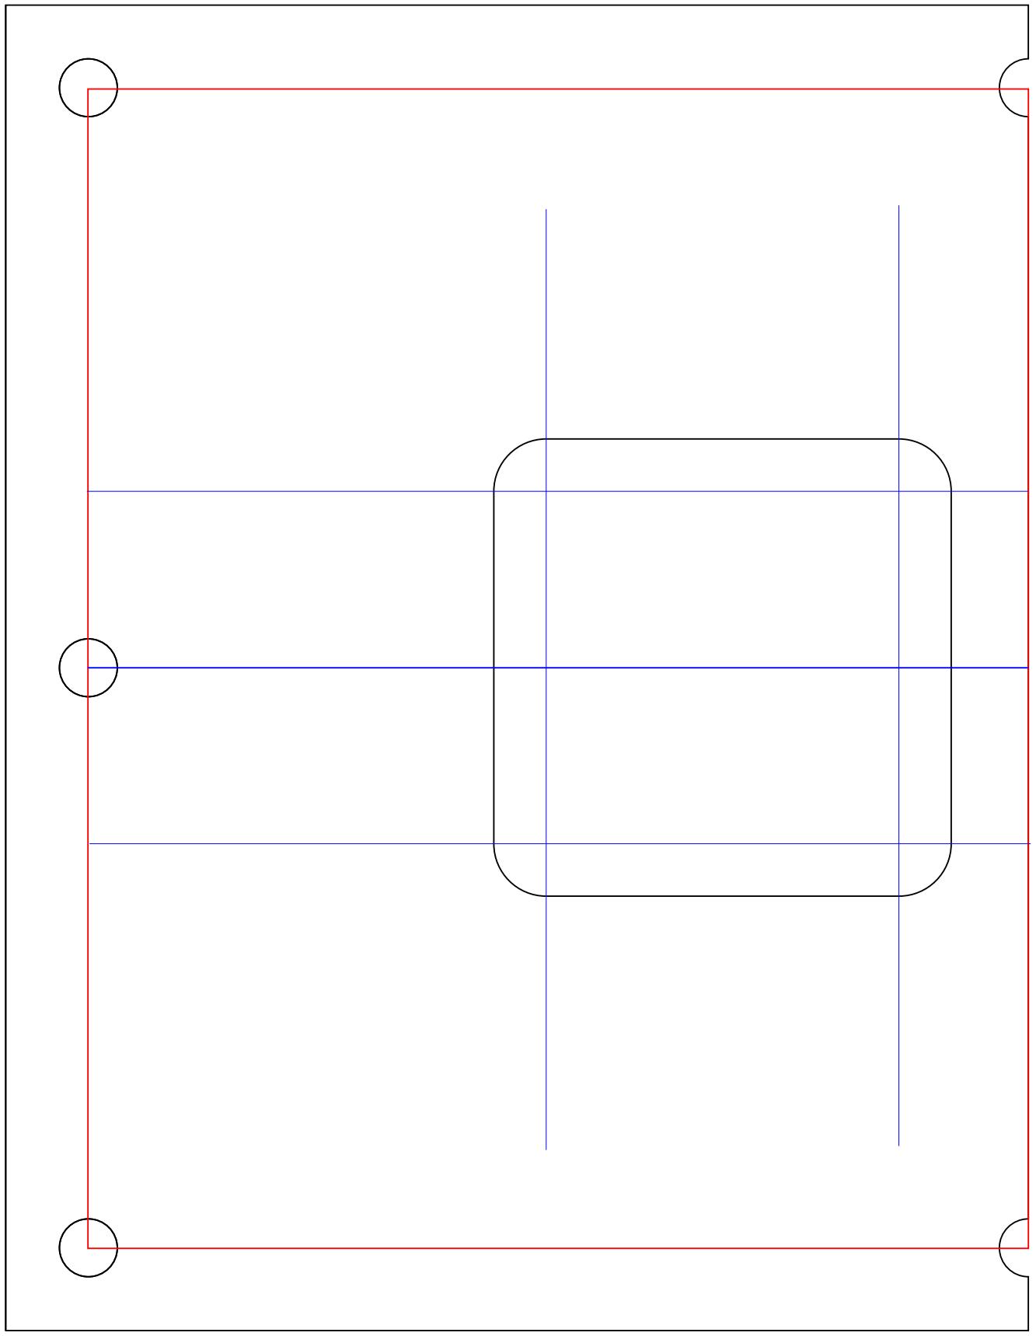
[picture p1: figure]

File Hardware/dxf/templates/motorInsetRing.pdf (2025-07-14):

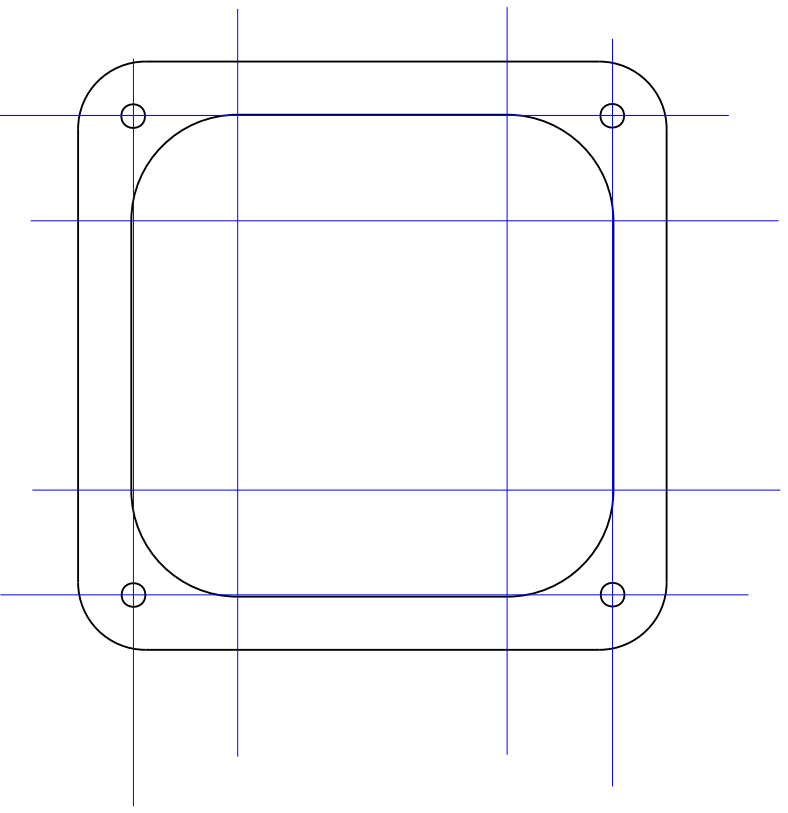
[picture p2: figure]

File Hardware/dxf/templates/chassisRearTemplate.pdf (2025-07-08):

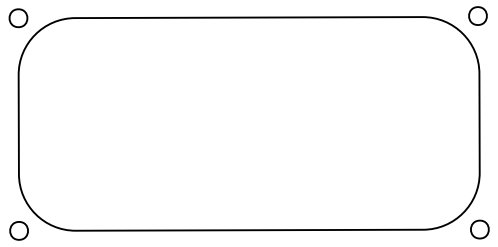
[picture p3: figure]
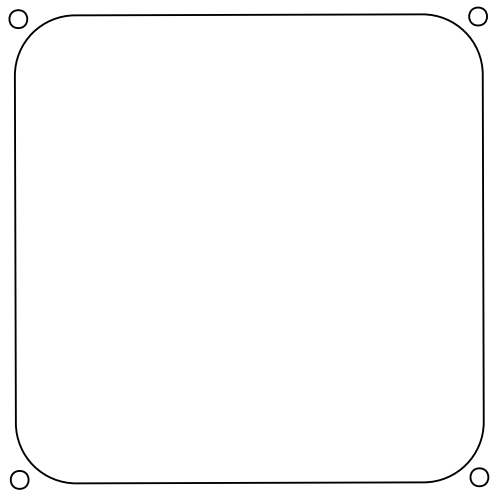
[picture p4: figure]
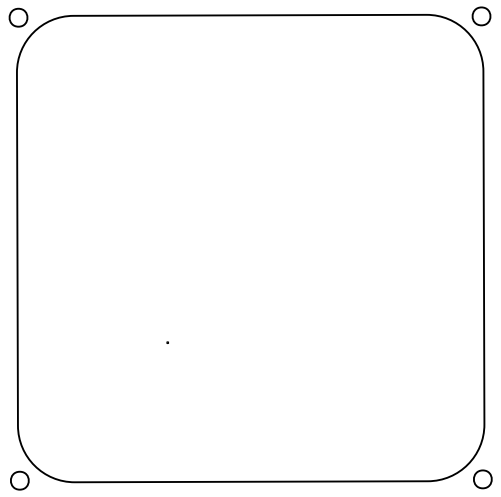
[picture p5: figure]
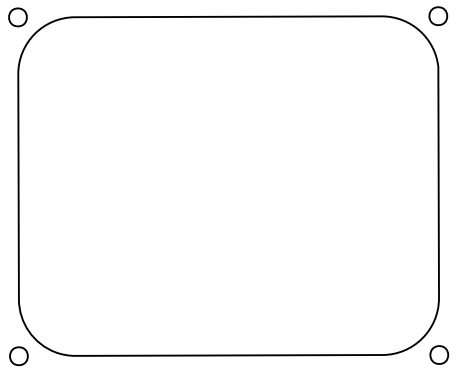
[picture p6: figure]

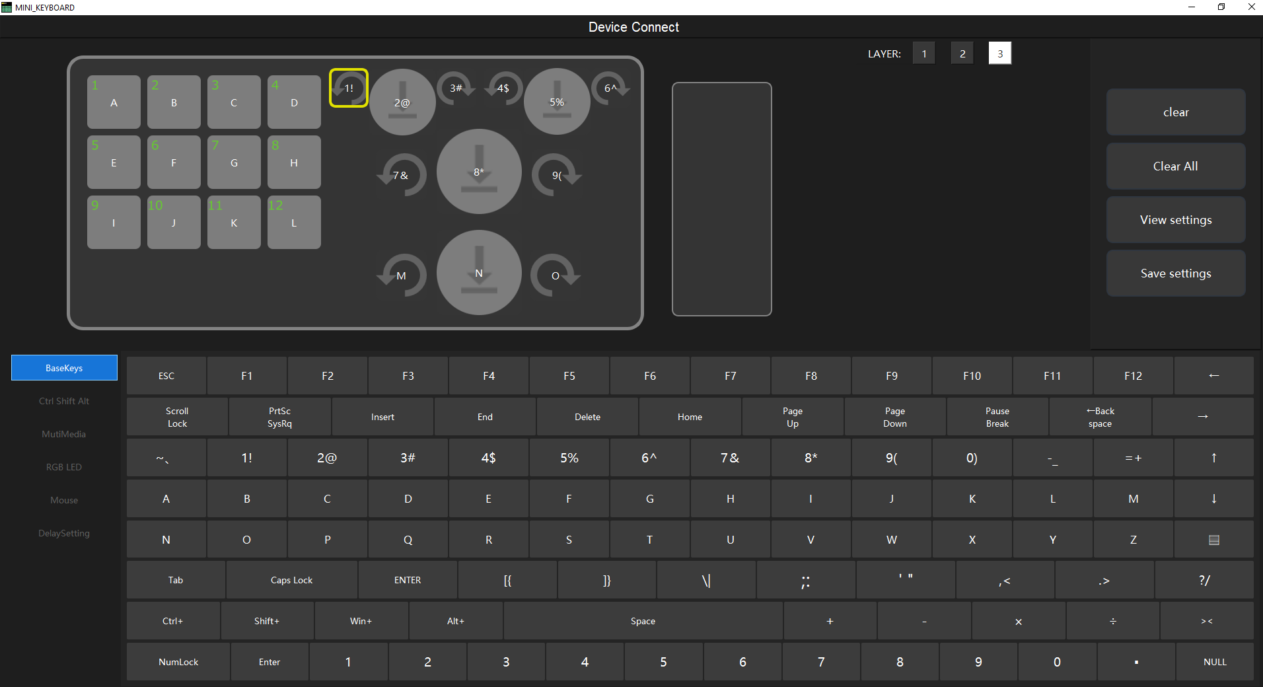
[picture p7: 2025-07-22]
Software/FacetHound_SD_Loader/usbToUART/keyboardSettings.png

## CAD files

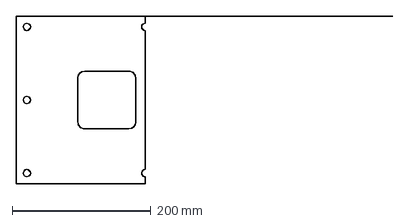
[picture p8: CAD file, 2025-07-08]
Hardware/dxf/templates/motorInsetMainInset.dxf
541.7 x 240.6 mm

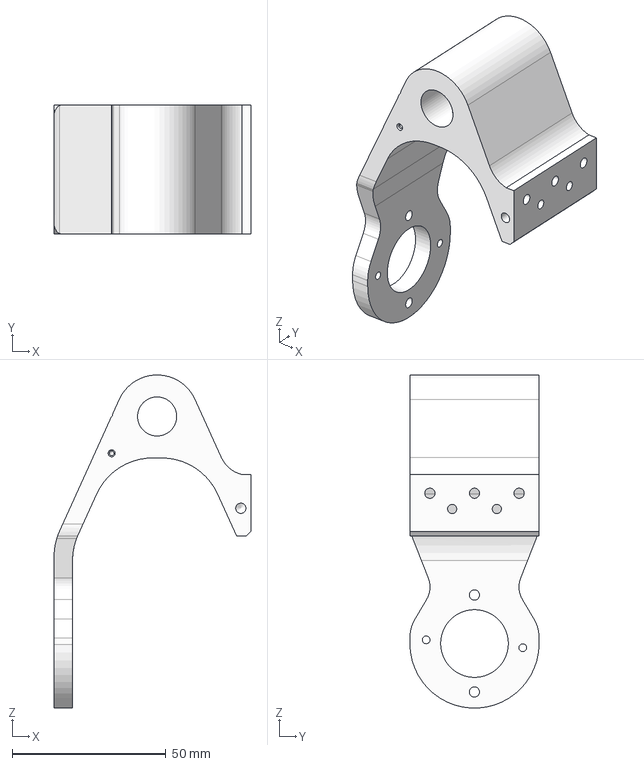
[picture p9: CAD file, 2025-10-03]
Hardware/step/toMachine/v8/pivotArm_main_v8.step
64.0 x 42.0 x 108.2 mm

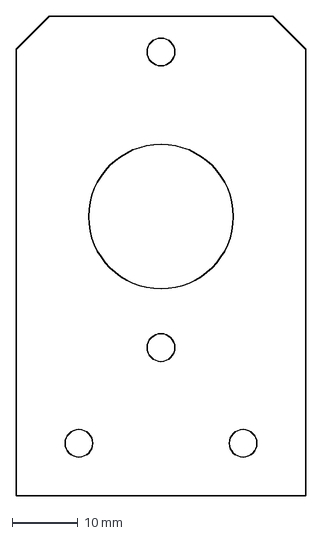
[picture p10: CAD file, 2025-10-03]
Hardware/dxf/mastAdapterPlate_flatStock.dxf
44.0 x 73.0 mm

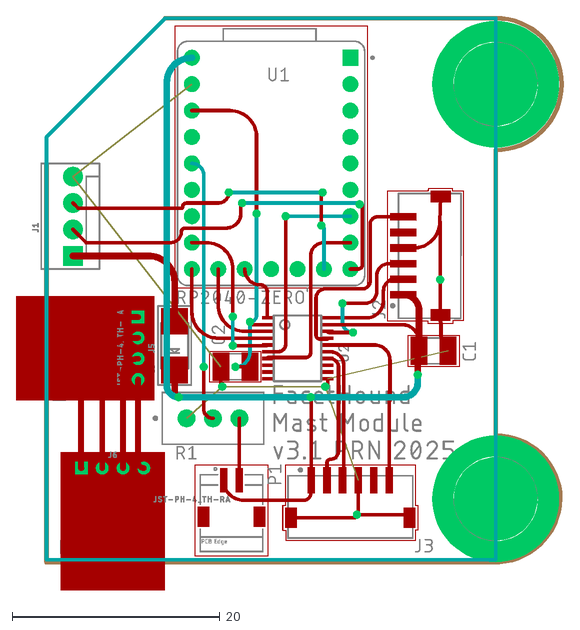
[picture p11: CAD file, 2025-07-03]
Hardware/pcb/MastModule.dxf
52.7 x 55.2

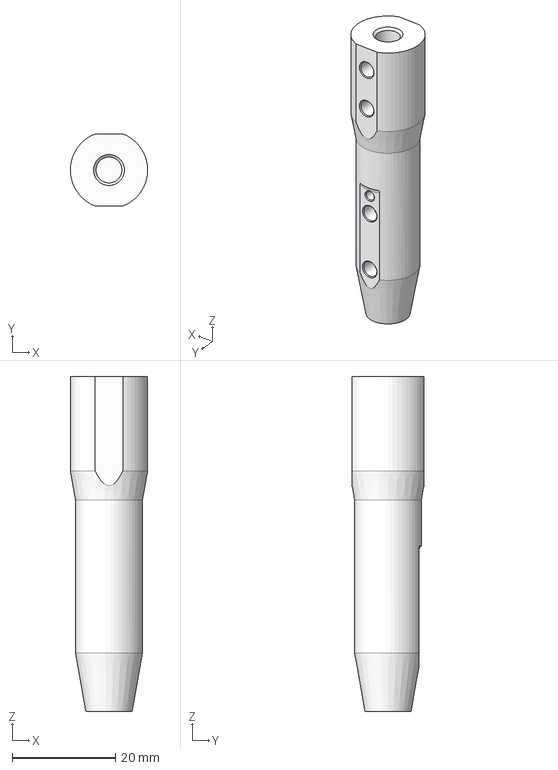
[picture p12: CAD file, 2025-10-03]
Hardware/step/toMachine/v8/twistMotorToDopShaft_v8.step
15.0 x 14.0 x 65.0 mm

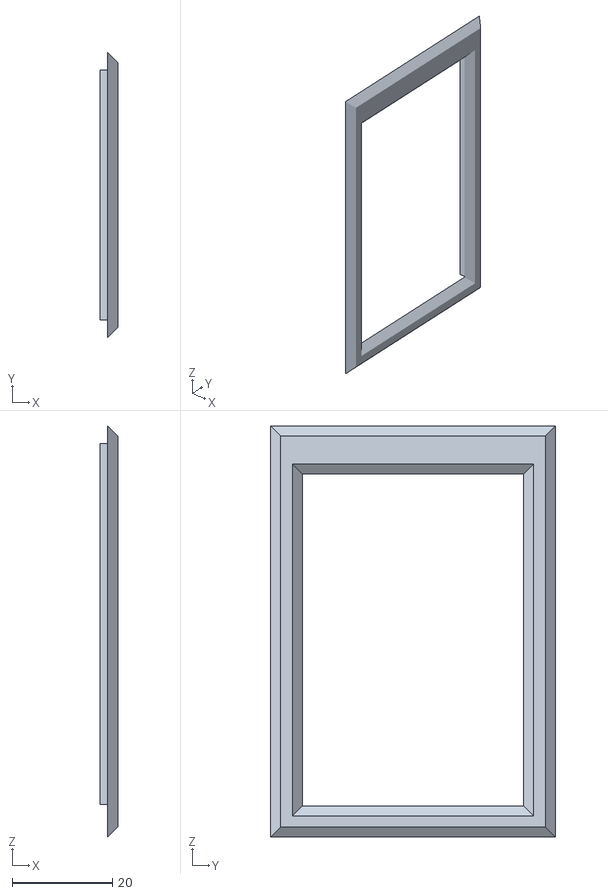
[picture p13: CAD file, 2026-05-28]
Hardware/step/toPrint/v7+/bezeladapter32tft.stl
3.50 x 56.8 x 82.0

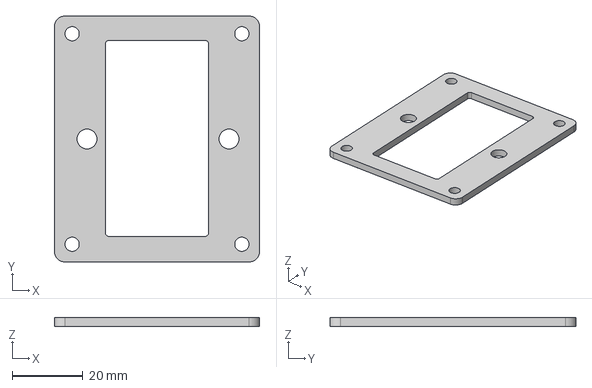
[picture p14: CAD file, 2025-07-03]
Hardware/step/toPrint/v7/chassisPowerPanel_v7.step
57.8 x 69.3 x 2.50 mm

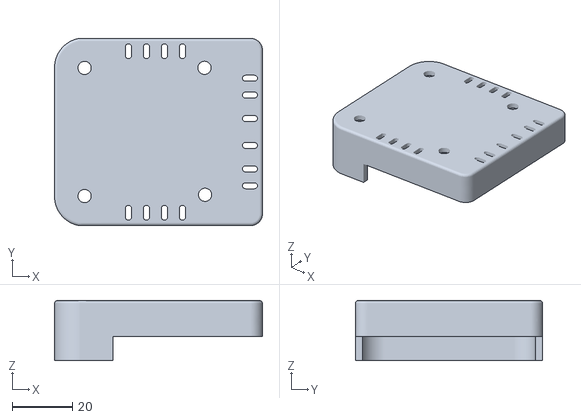
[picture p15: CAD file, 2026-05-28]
Hardware/stl/mastPCBCover_v8+.stl
69.3 x 62.4 x 20.0

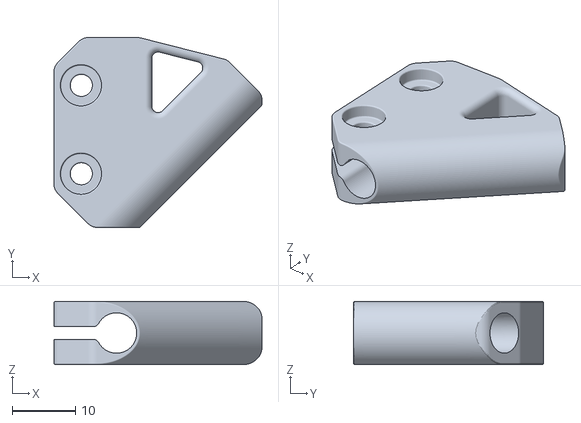
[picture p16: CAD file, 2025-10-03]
Hardware/stl/v8/tableAdapter_635mmDops.stl
32.9 x 30.1 x 10.0

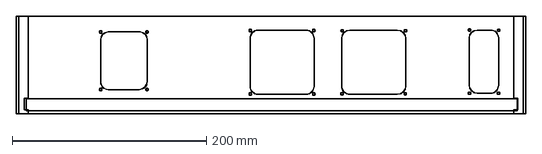
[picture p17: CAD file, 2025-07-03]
Hardware/dxf/chassisRearPanel.dxf
523.7 x 100.0 mm

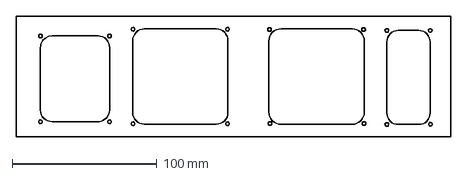
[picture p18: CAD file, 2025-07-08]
Hardware/dxf/templates/chassisRearTemplate.dxf
300.0 x 83.5 mm

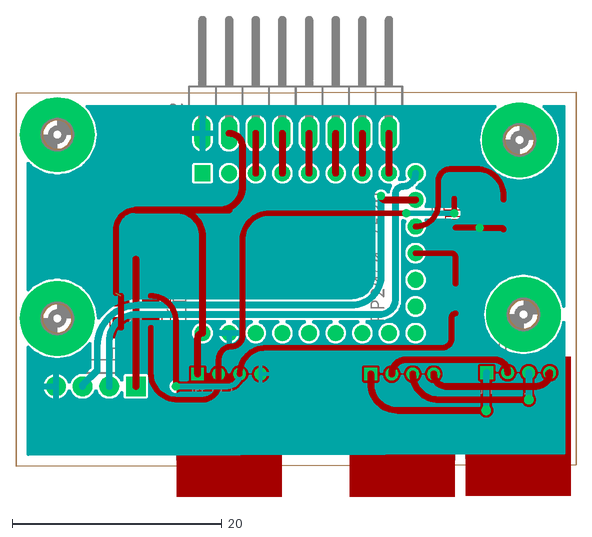
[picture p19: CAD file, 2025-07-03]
Hardware/pcb/Display-KeyboardModule.dxf
53.4 x 45.8

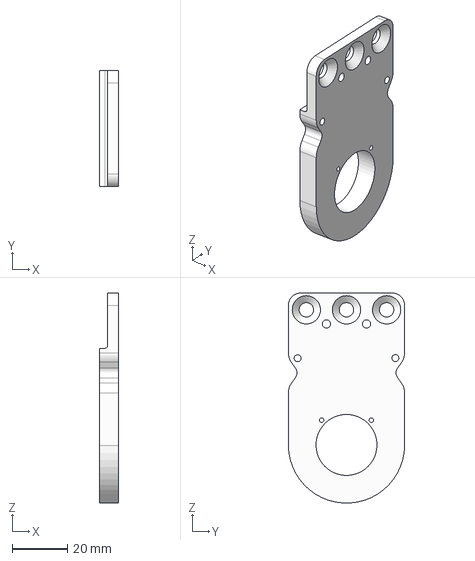
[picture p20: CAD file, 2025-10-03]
Hardware/step/toMachine/v8/pivotArm_secondary_v8.step
7.00 x 42.0 x 75.9 mm

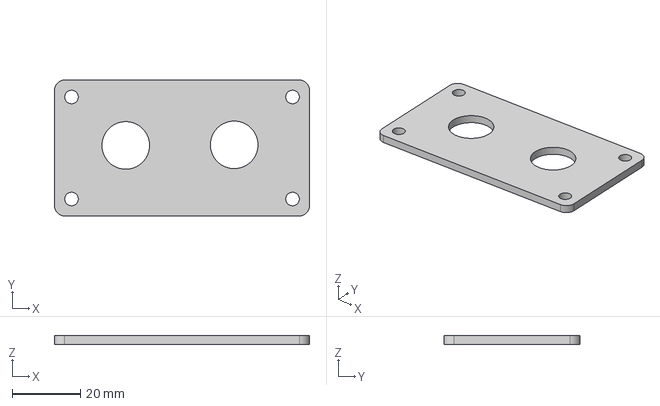
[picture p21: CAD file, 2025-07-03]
Hardware/step/toPrint/v7/chassisPlumbingPanel_v7.step
75.0 x 40.0 x 2.50 mm

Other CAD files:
Hardware/stl/displayMiddleLayer_v8.stl
Hardware/stl/v8/transferJigBody.stl
Hardware/dxf/chassisTop_v7.dxf
Hardware/dxf/templates/motorInsetRing.dxf
Hardware/dxf/chassisConnectionsPanel_v7.dxf
Hardware/dxf/chassisFanPanel_v7.dxf
Hardware/dxf/chassisPowerPanel_v7.dxf
Hardware/dxf/chassisSidePanel.dxf
Hardware/dxf/chassisTubingPanel_v7.dxf
Hardware/dxf/motorHangPlate_v7.dxf
Hardware/pcb/BaseModule.dxf
Hardware/pcb/USBHostModule.dxf
Hardware/pcb/mastPCB.dxf
Hardware/step/toMachine/v7/mastSlideAdapterPlate.step
Hardware/step/toMachine/v7/motorHangPlate_v7.step
Hardware/step/toMachine/v7/pivotArmYoke_v7.step
Hardware/step/toMachine/v7/pivotArm_main_v7.step
Hardware/step/toMachine/v7/pivotArm_secondary_v7.step
Hardware/step/toMachine/v7/twistMotorToDopShaft_v7.step
Hardware/step/toMachine/v7/v7_headShell.step
Hardware/step/toMachine/v8/mastSlideAdapterPlate_v8.step
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

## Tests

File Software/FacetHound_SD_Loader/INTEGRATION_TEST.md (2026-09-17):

# Three-module integration test

Bring the machine up in layers. A suspected PCB short is a power fault first,
not a firmware or communications problem.

## 1. Isolate the short before connecting controllers

1. Disconnect USB, external power, motors, drivers, display, mast, keyboard,
   SD reader, and every inter-board cable from the suspect PCB.
2. Inspect both sides under magnification for solder bridges, reversed parts,
   conductive debris, damaged vias, and connector pins touching planes.
3. With power removed, measure resistance from each power rail to ground in
   both probe polarities. Record the readings rather than relying only on the
   continuity beeper; capacitors may initially look like a short while charging.
4. Split the board electrically wherever connectors, jumpers, ferrites, or
   zero-ohm links permit, then repeat the measurements to narrow the section.
5. Power only a rail whose voltage and polarity are known, using a bench supply
   with a conservative current limit. Stop if the supply immediately current
   limits or a component heats unexpectedly. A thermal camera, careful IPA
   evaporation, or freeze spray can identify the heating part without raising
   the current aggressively.
6. Verify every required rail at its test point and confirm no unpowered rail
   is being back-fed through a UART, USB cable, or GPIO before reconnecting a
   controller.

Do not use resistance mode on a powered circuit. Do not inject voltage into an
unknown signal net, and do not connect USB and external supplies together until
their grounding and back-feed paths are understood.

## 2. Controller-only smoke tests

Test each controller separately before joining them:

- **Display:** power and restart it several times. Confirm the complete splash,
  persisted UI mode, and no reset loop.
- **Mast:** verify 3.3 V and sensor supplies, then confirm encoder clock/CS
  activity. Open the mast's USB serial port during reset to enable automatic
  diagnostic mirroring, then confirm `@tip`, `@twist`, and `@force` records.
  No special bench build is required.
- **Base:** leave motor power disabled. Connect its native USB and run
  `tools/base_module_console.py`; `state` must return a valid snapshot and
  `stop` must acknowledge.
- **Keyboard host:** power its protected keyboard VBUS without the base UART
  connected. Confirm 5 V VBUS and 3.3 V controller rails remain stable, then
  attach a keyboard and check for USB-host resets or excess supply current.

## 3. Base plus mast

Wire common ground first, then mast TX8 to base RX2 and base TX3 to mast RX9.
Both sides use 115200 baud, 3.3 V TTL.

Run the PC console:

```text
stream 250
```

Pass criteria:

- `@IO,mast_rx=...` increases continuously.
- `mast_link=up` and `mast_age_ms` remains well below 500.
- `tip` changes smoothly through mast motion.
- `actual` follows twist motion and crosses the wheel rollover without a large
  false jump.
- `force` increases with sensor load and stays below 140000.
- The base does not repeatedly reset or print malformed-line errors.

If `mast_rx` stays zero, check crossed TX/RX, shared ground, 115200 baud, and
3.3 V idle-high levels. If bytes rise but values do not change, capture the raw
UART and verify each line begins with `@` and ends with newline.

## 4. Add display, keyboard, and SD

1. Add the display UART: base TX5 to display RX9, base RX4 from display TX8,
   plus common ground. The display link is 460800 baud. On the v8 PCBs the
   four-conductor cable is fully reversed: base connector pins 1/2/3/4 land on
   display connector pins 4/3/2/1. Confirm that mapping with continuity before
   applying power.
2. Confirm telemetry appears in Classic, Dynamic, and Static modes.
3. Add the dedicated keyboard bridge UART: bridge TX0 to base RX6 and bridge
   RX1 to base TX7. Verify A opens Settings, B/C change tiers, H offsets marks,
   and the twist wheel operates the menu. `STATUS` should show
   `keyboard_link=up` even before a key is pressed.
4. Add the SD reader on base GPIO8-11 and load a known ASC/FHC pair. Confirm the
   loaded facet, target tip/index, dynamic highlight, and tier buttons agree.

With the base USB console open, send `STATUS`. A healthy display return path
reports `display_link=up`; repeated `STATUS` calls about a second apart show
`display_rx` increasing because the display sends a heartbeat. If the display
updates but `display_link=down`, only the base-to-display direction works. If
the display stays stale but `display_link=up`, only display-to-base works or the
base TX/display RX conductor is wrong.

The current base also reports `display_roundtrip`. When this is `up`, the base
has sent a query which the display parsed and answered, proving both UART
directions. With sensors disconnected, ordinary values remain constant even on
a healthy display. Send `TEST DISPLAY ON` to animate synthetic tip, index, Z,
RPM, and flow values; send `TEST DISPLAY OFF` afterward.

`TRACE ON` mirrors complete incoming mast, keyboard, and display records to the
PC as `@RAW,...` lines. Use it briefly to distinguish malformed framing from a
silent electrical link, then send `TRACE OFF`. The base reports UART FIFO
overflow latches as `rx_overflow=MxKxDx` in each status record.

For mast or keyboard connector trials that would otherwise require reflashing
several modules, the two `*_UART_SWAP_TRIAL` constants at the top of the base
sketch reverse only the selected base GPIO pair. Upload only the base and test
one link at a time. The normal v8 settings are both `false`.

## 5. Add motion last

Keep mechanical loads clear and use the lowest practical driver current during
first motion tests. Add one subsystem at a time: index, Z, pump, then lap RS-485.
After each connection, repeat `state`, a small jog, and `stop`. Do not proceed
to the next motor if supply current, direction, encoder feedback, or emergency
stop behavior is wrong.

The USB console API and telemetry definitions are in
`baseChassisModule/PC_USB_API.md`. Full base wiring is in
`baseChassisModule/BASE_WIRING_AND_TEST.md`.

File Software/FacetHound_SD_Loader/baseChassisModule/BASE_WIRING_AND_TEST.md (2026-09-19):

# Base module wiring and bench test

The keyboard remains a dedicated UART module. The Pico is not a USB keyboard
host. Its native USB connector is used only for programming and the optional
PC diagnostic console.

## Signal map

All UART logic must be 3.3 V TTL and every module needs a common ground.

| Device / signal | Base GPIO | Notes |
|---|---:|---|
| Keyboard UART TX | 7 | Base TX to keyboard-host RX GPIO1 |
| Keyboard UART RX | 6 | Keyboard-host TX GPIO0 sends `D,<HID>` events here |
| Display UART TX | 5 | Base to display, 460800 baud |
| Display UART RX | 4 | Display to base, 460800 baud |
| Mast UART TX | 3 | Base to mast, 115200 baud |
| Mast UART RX | 2 | Mast to base, 115200 baud |
| Lap TTL TX / RX | 8 / 9 | Hardware UART1 at the v9 `ESC.TTL` header; external automatic-direction RS-485 module; BLD-510B, 9600 8N1 |
| SD CS | 10 | v9 microSD header pin 2; PIO-backed software SPI |
| SD MOSI | 11 | v9 microSD header pin 3, matching photographed reader |
| SD SCK | 12 | v9 microSD header pin 4, matching photographed reader |
| SD MISO | 13 | v9 microSD header pin 5; PIO-backed software SPI |
| Twist STEP / DIR / EN / shared UART | 1 / 0 / 14 / 28 | TMC2208-compatible axis; UART through 1 kΩ |
| Z STEP / DIR / EN / shared UART | 16 / 17 / 18 / 15 | TMC2208-compatible axis; UART through 1 kΩ |
| Pump STEP / DIR / EN / shared UART | 20 / 21 / 22 / 19 | TMC2208-compatible axis; UART through 1 kΩ |
| PC diagnostics | Native USB | USB CDC only; not the keyboard path |

This map comes from `Hardware/pcb/v9/BaseModule.sch`.
The v9 board does not connect GPIO 26/27. The microSD header is, in pin order,
3V3, CS, MOSI, SCK, MISO, GND for the photographed straight-through reader.
The old software labels had SCK/MOSI reversed. Do not swap the power pins or
use the old GPIO 8-11 SD map with v9. No card-detect pin is required.

For the opposite end of the mast link, connect mast TX GPIO8 to base RX GPIO2
and mast RX GPIO9 to base TX GPIO3. The matching streaming records and numeric
ranges are documented in [the mast README](../mastModule/README.md).

## Keyboard protocol

The keyboard module sends one newline-terminated record per action:

```text
D,4
```

The second field is the HID usage number configured in
[`../usbToUART/keyboardSettings.png`](../usbToUART/keyboardSettings.png). See
[KEYBOARD_MAP.md](KEYBOARD_MAP.md) and
[keyboard_map.svg](keyboard_map.svg) for the physical layout and action map.

## USB bench console

`tools/base_module_console.py` talks to the base module's native USB CDC port.
It displays raw traffic, decoded state, I/O counters, and supports controlled
motor jogs. It does not intercept the keyboard UART.

The console is a reference client for a documented PC-control interface. See
[PC_USB_API.md](PC_USB_API.md) for framing, every command and response, state
field definitions, safety guidance, and a minimal client example.

For Spyder, open the script, set `SERIAL_PORT = "COM5"` near the top, and run
the file. `AUTO` also works when exactly one likely Pico serial port is present.
Install pyserial in Spyder's Python environment if needed:

```text
python -m pip install pyserial
```

Useful console commands:

```text
state
stream 250
stream off
key A
key 7
jog twist 1
jog z 200
rpm 20
motor cw
flow 100
pump fwd
stop
```

For integration diagnostics, `MOTOR PROBE` requests BLD-510B actual-speed
register `0x8018` without starting the lap. `MOTOR STATUS` reports validated
Modbus replies, CRC errors, exceptions, timeouts, byte counts, and the last raw
reply. `STATUS` includes the same `@MOTOR` record. A valid Modbus exception
proves the electrical link even though it indicates a rejected request.

The v9 `ESC.TTL` header is pin 1 GND, pin 2 GP9/RX, pin 3 GP8/TX, pin 4
3.3 V. On automatic-direction converter boards whose UART pins are labelled
from the converter's perspective, connect converter `TXD` to header pin 2
(Pico RX) and converter `RXD` to header pin 3 (Pico TX). Do not connect the
two transmitters label-to-label. The lap port uses the Pico's native UART1 so
it does not consume two additional PIO state machines.

The v9 schematic ties both PDN/UART pads of each TMC2208-compatible carrier
together, then connects that node through 1 kΩ to one Pico GPIO (twist GP28,
Z GP15, pump GP19). The electrical routing therefore supports single-wire
half-duplex UART. Twist and Z release their transmit-only `SerialPIO` links
after startup configuration and run through STEP/DIR plus hardware EN. The
pump retains its transmit-only UART because its velocity and direction are
changed through TMC registers at runtime. Firmware does not claim TMC readback
until a tested single-pin turnaround implementation is added.

Genuine SilentStepStick-compatible carriers expose PDN/UART on the header and
need no carrier modification with this PCB. Some clone carriers require their
on-board UART solder jumper to be bridged. Verify continuity from the carrier's
PDN/UART connection to the PCB-side 1 kOhm UART resistor before modifying it;
the required jumper is carrier-specific.

Use `SD RETRY` after inserting a card, `SD STATUS` to inspect initialization,
and `SD LIST` to verify that the root directory and supported `.asc`/`.fct`
files are readable. Failed automatic initialization retries are limited to one
per second so a missing card does not stall the rest of the control loop.

`quit`, Ctrl+C, and EOF send `STREAM OFF` and `STOP` before closing. Keep the
machine mechanically safe during bench tests: begin with motors unloaded or
disabled, use small jogs, and retain physical power cutoff access.

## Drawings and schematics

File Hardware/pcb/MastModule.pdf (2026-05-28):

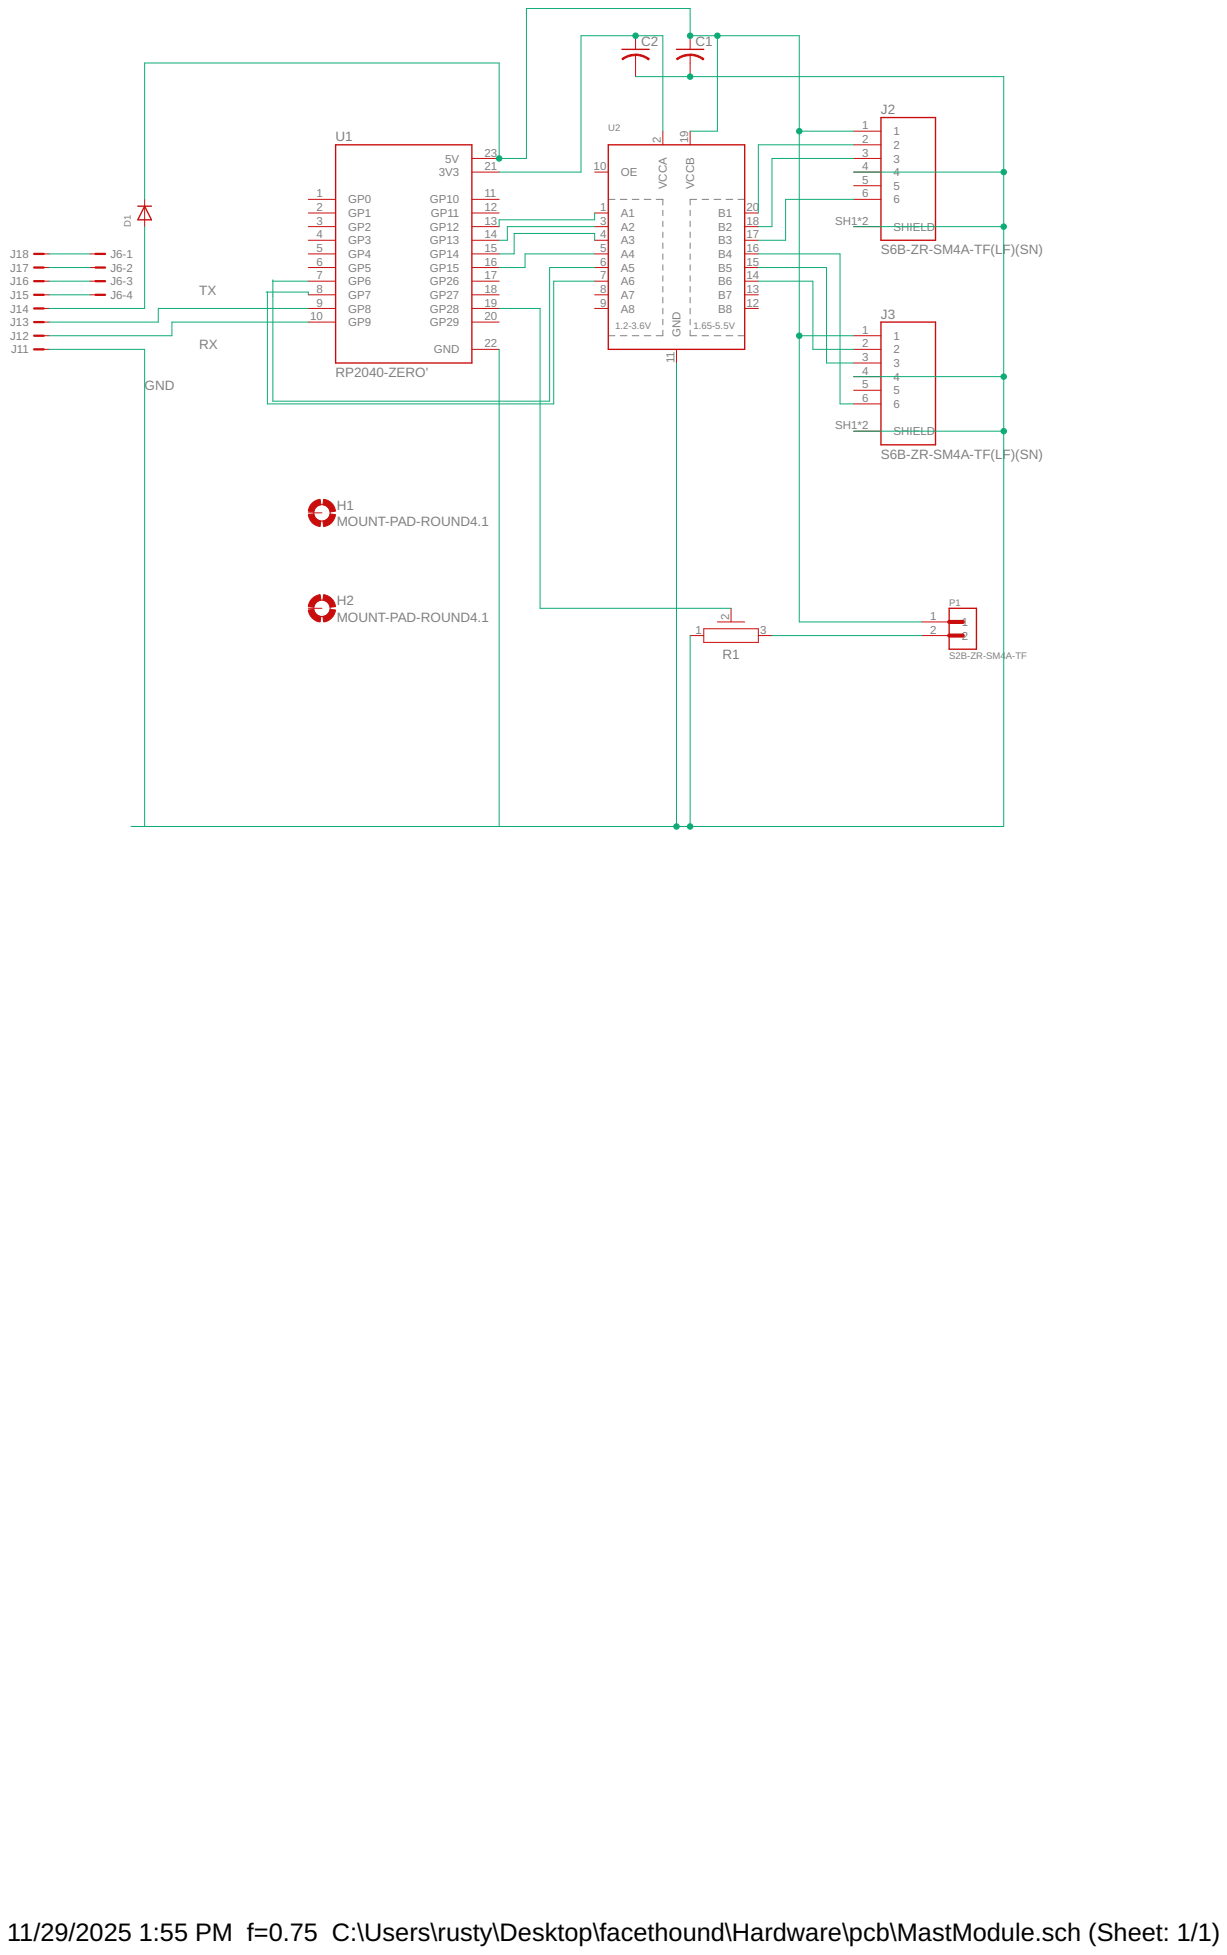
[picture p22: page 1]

3 | S6B-ZR-SM4A-TF(LF)(SN) MOUNT-PAD-ROUND4.1 MOUNT-PAD-ROUND4.1

11/29/2025 1:55 PM f=0.75 C:\Users\rusty\Desktop\facethound\Hardware\pcb\MastModule.sch (Sheet: 1/1)

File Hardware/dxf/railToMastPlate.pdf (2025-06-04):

7
52

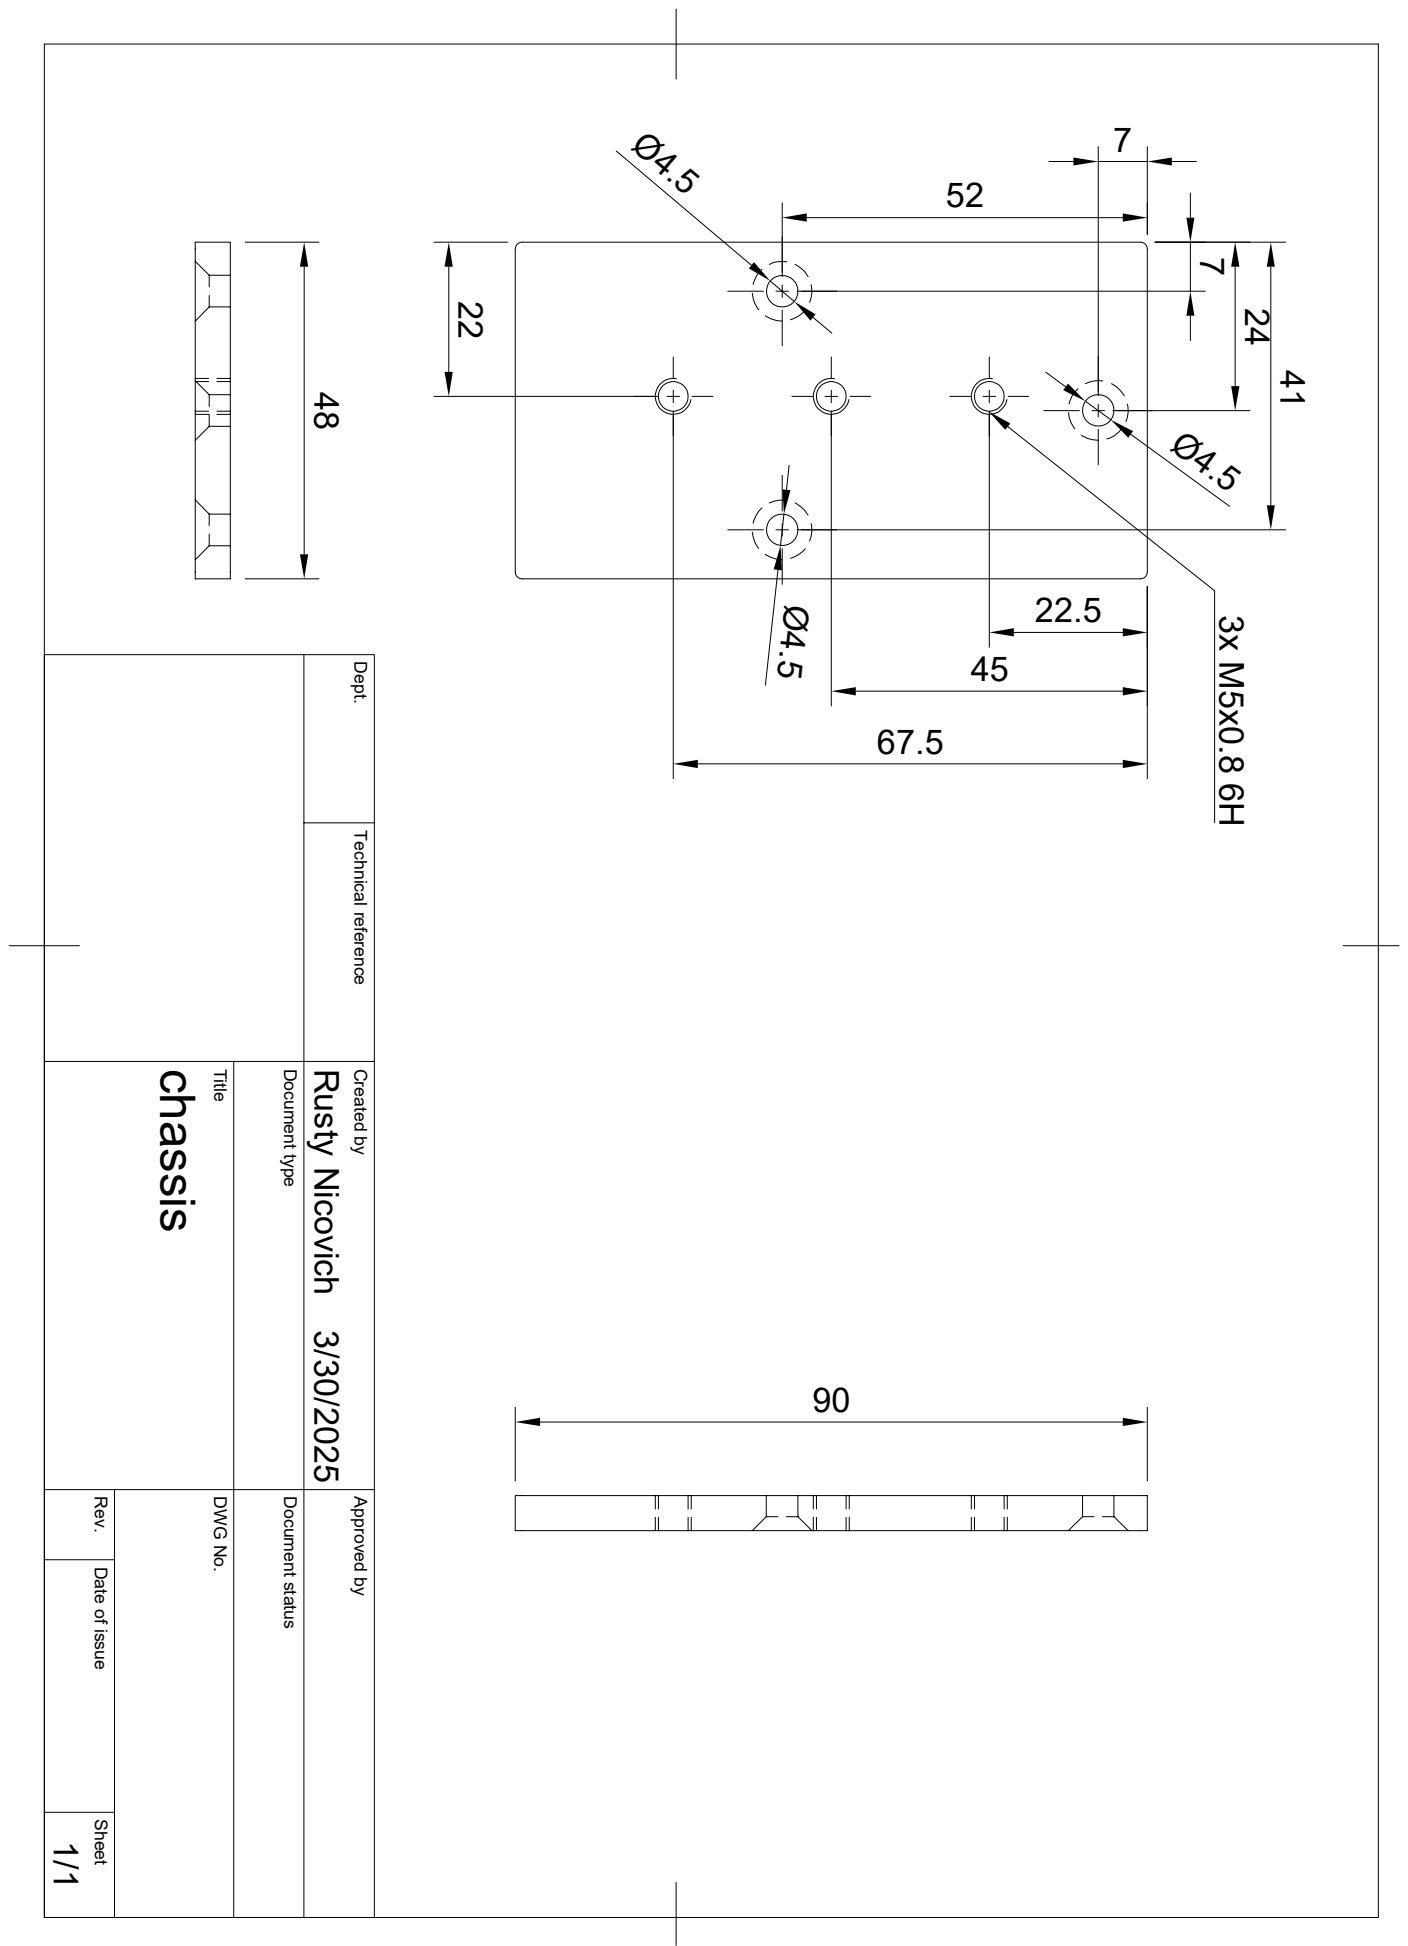
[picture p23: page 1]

Dept. Technical reference Created by Approved by Title DWG No. Document type Document status Rev. Date of issue Sheet 3/30/2025 1/1 chassis Rusty Nicovich 3x M5x0.8 6H 48

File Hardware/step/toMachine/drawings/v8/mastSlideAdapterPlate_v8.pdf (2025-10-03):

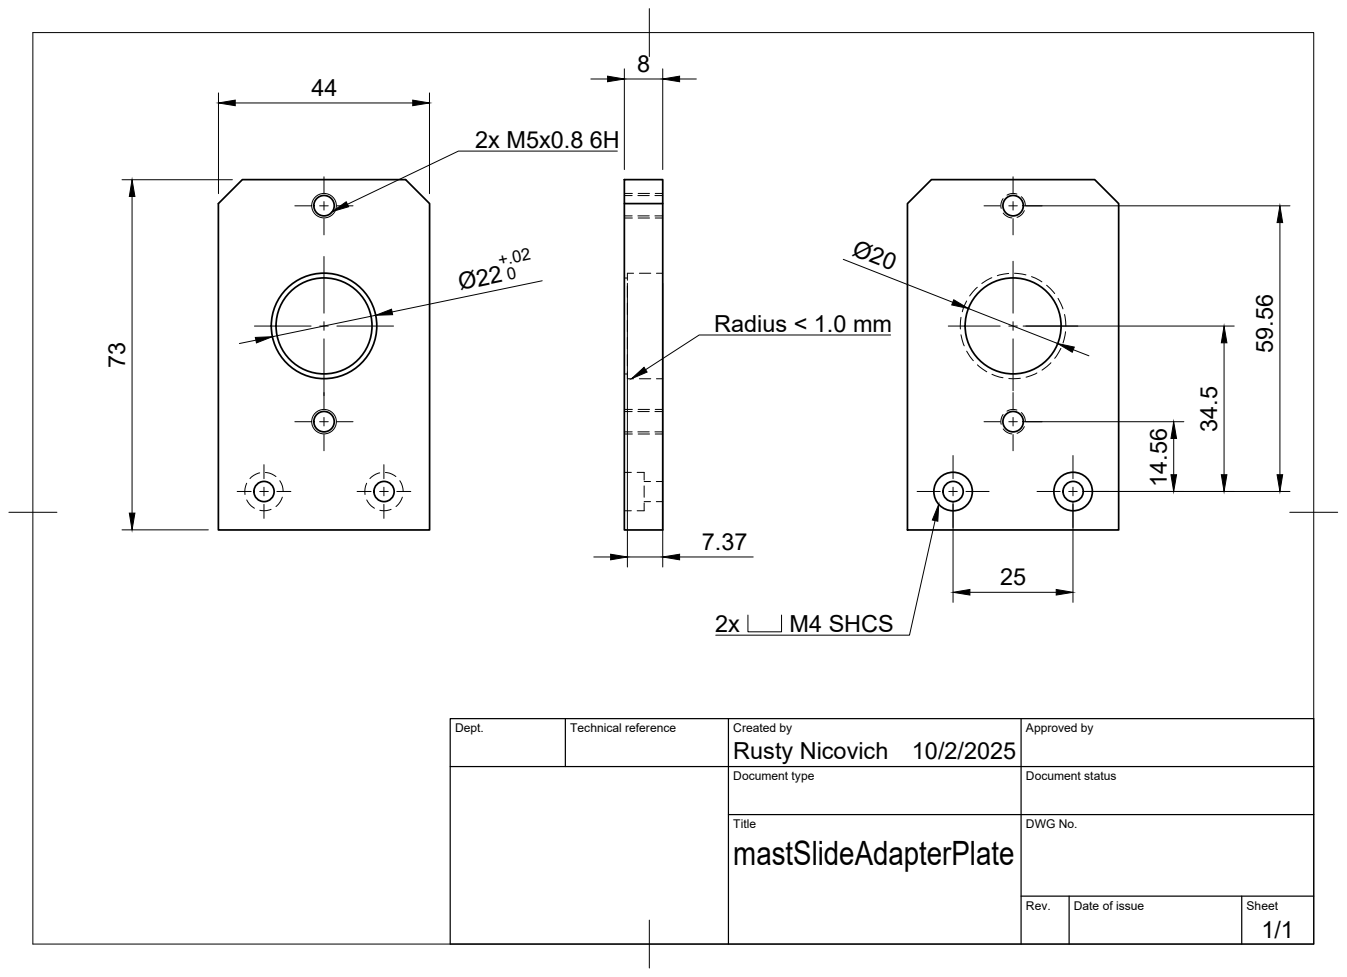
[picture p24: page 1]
Rusty Nicovich 73; M4 SHCS; Radius < 1.0 mm

Dept. | Technical reference | Created by 10/2/2025 | Approved by

Document type | Document status

Title mastSlideAdapterPlate | DWG No.

Rev. | Date of issue | Sheet 1/1

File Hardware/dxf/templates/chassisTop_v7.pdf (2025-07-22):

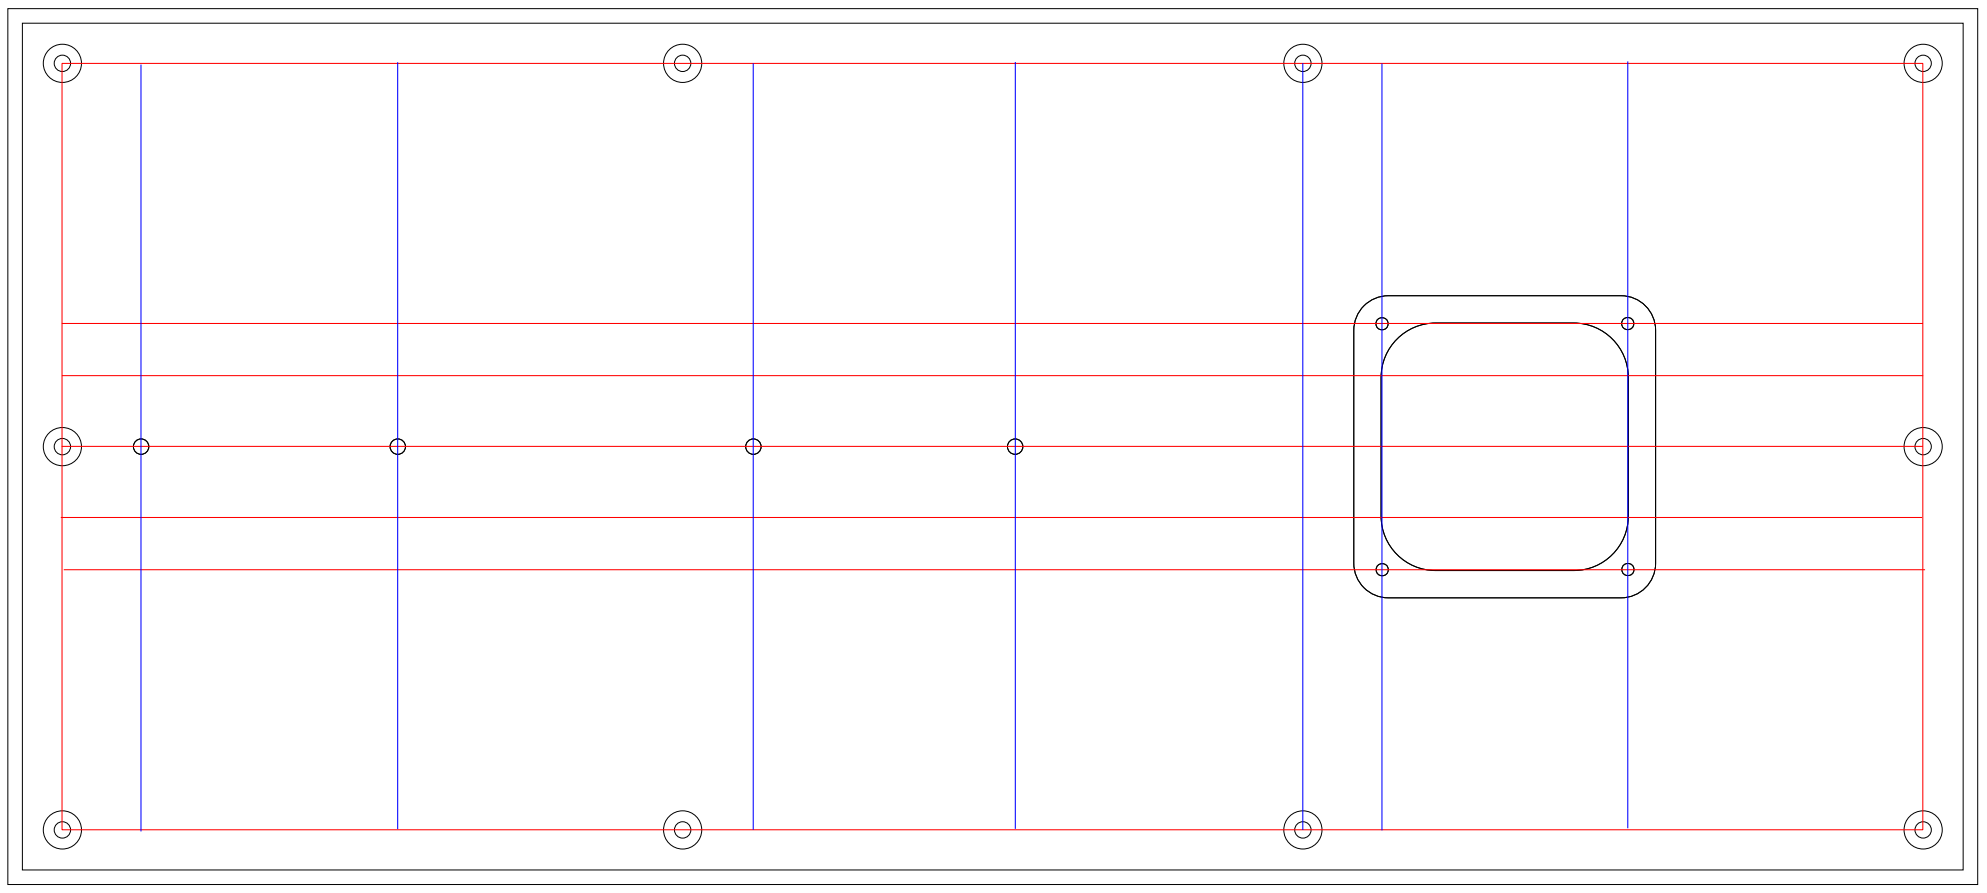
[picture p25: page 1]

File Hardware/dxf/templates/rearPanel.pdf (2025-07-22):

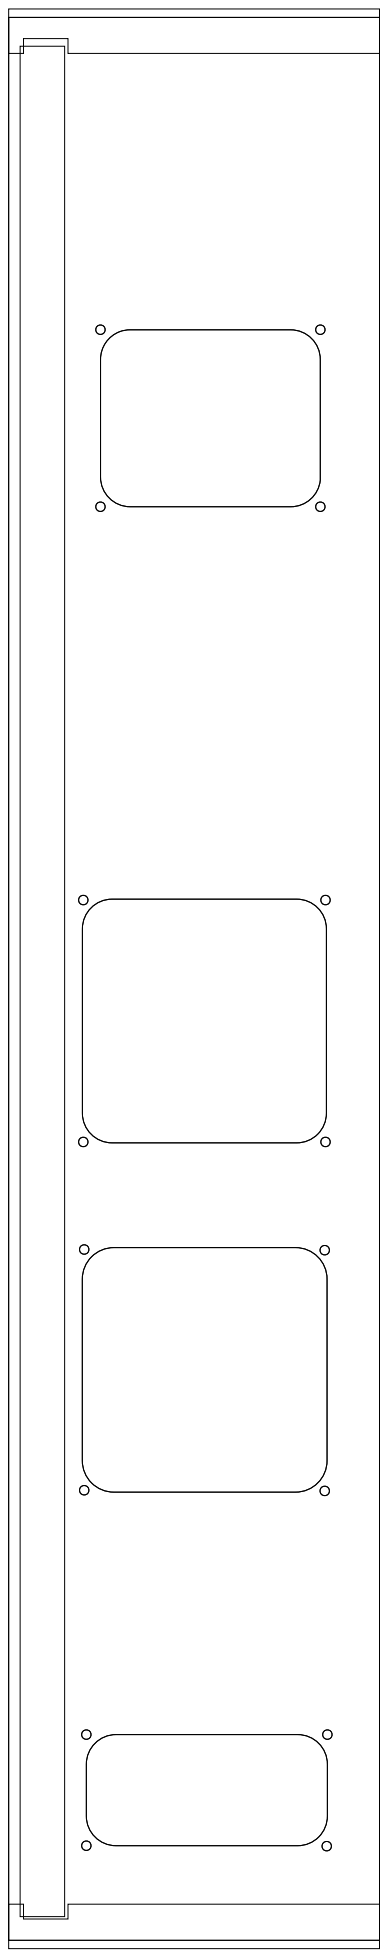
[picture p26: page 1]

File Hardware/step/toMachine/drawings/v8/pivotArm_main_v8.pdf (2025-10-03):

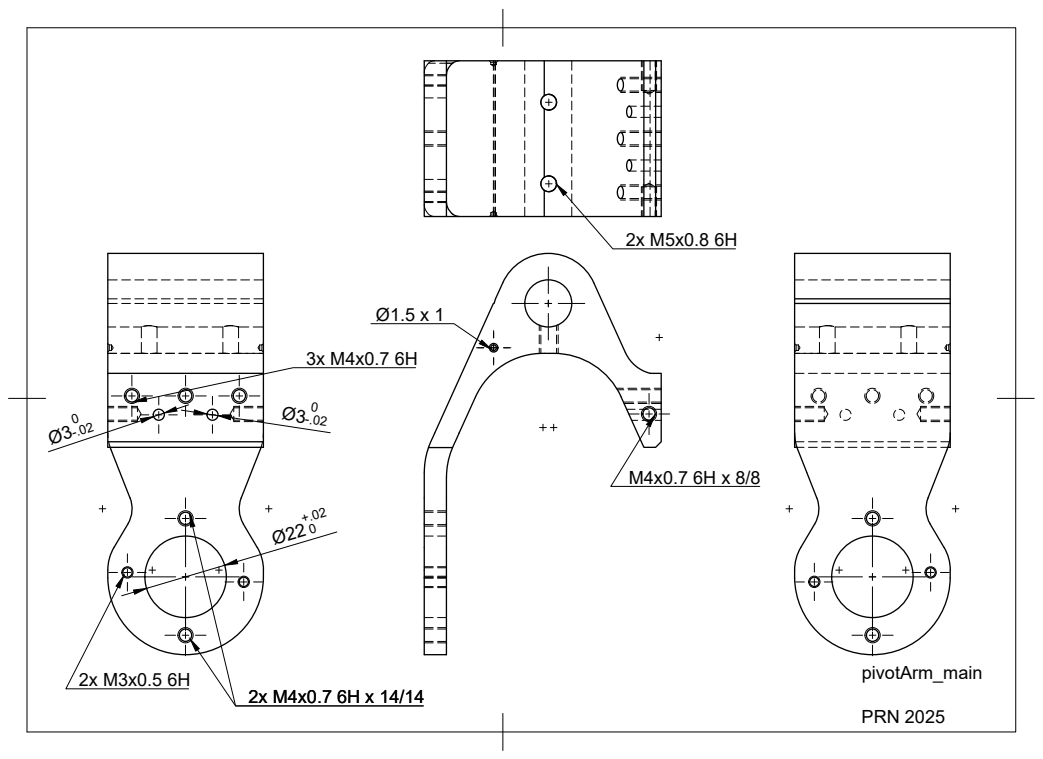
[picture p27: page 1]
PRN 2025

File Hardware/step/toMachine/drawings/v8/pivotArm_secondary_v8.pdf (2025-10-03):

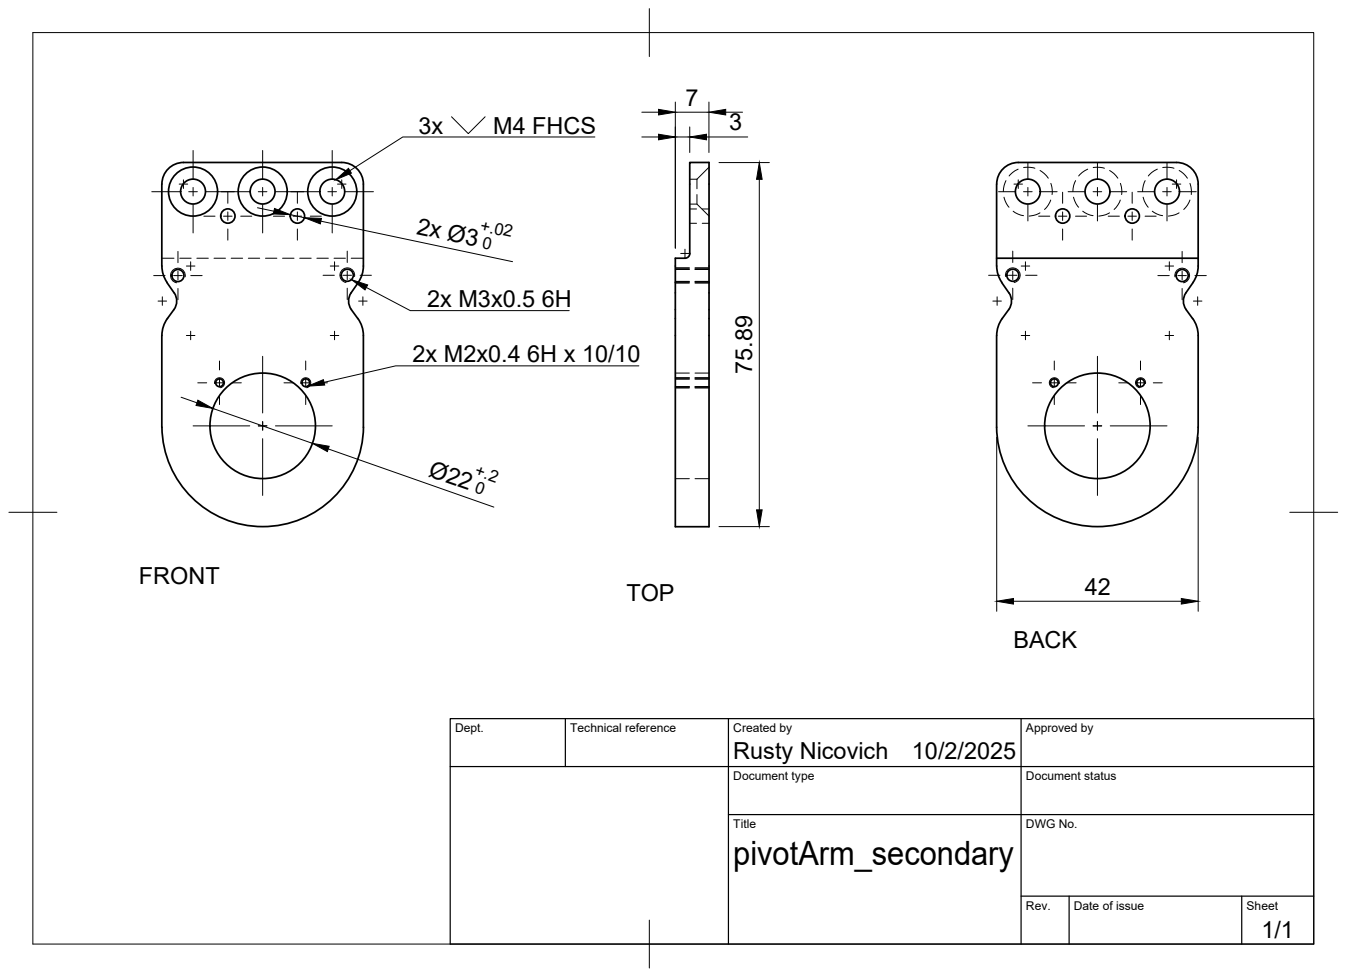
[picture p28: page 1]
M4 FHCS; TOP; 42 FRONT

Dept. | Technical reference | Created by Rusty Nicovich 10/2/2025 | Approved by

Document type | Document status

Title pivotArm_secondary | DWG No.

Rev. | Date of issue | Sheet 1/1

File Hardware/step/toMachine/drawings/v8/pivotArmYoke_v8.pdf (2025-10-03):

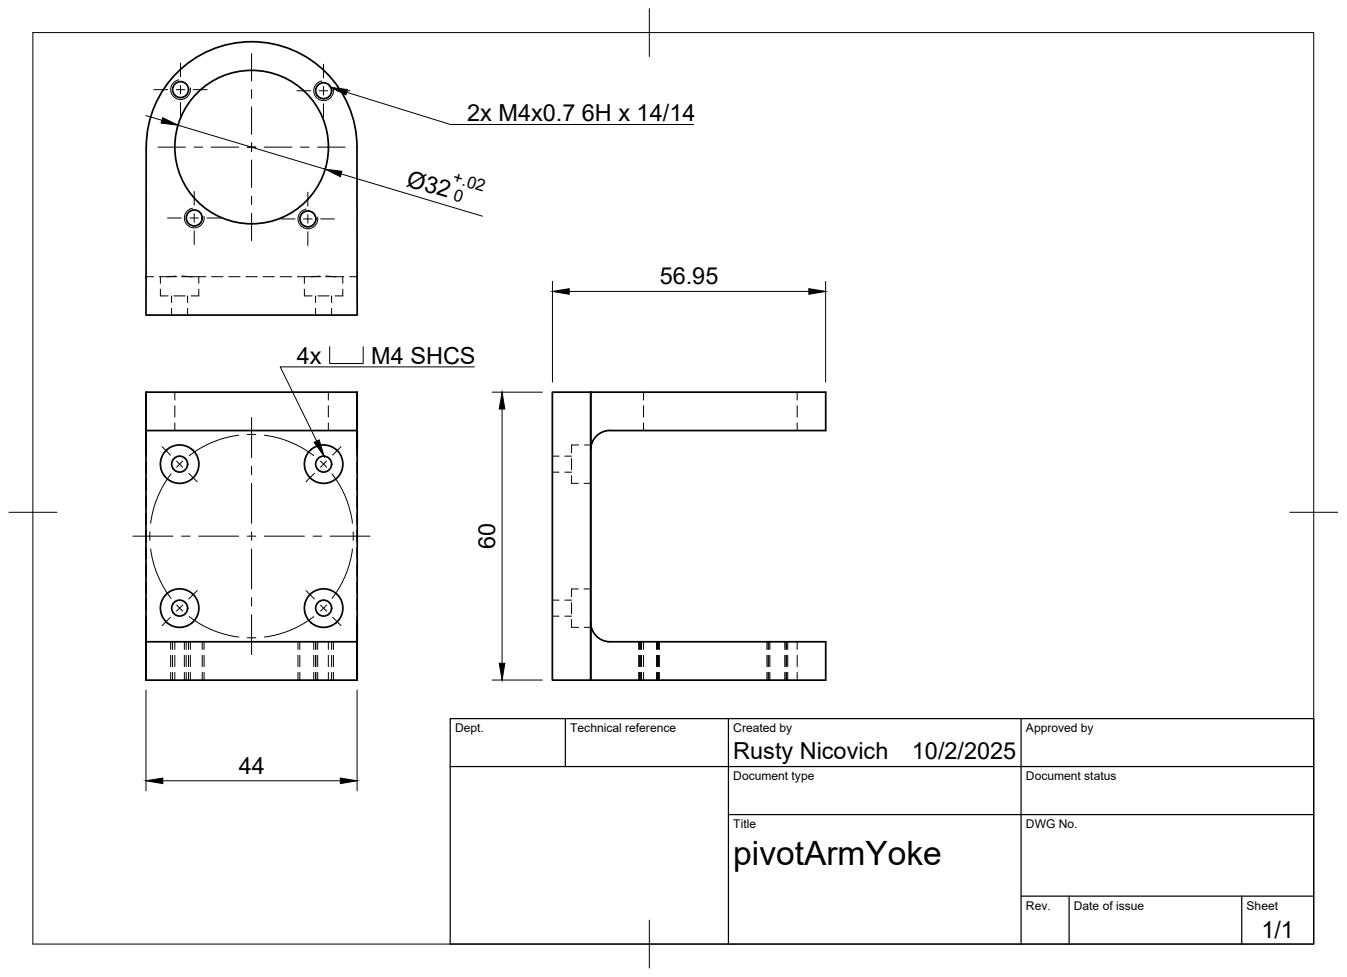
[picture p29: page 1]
M4 SHCS

Dept. | Technical reference | Created by Rusty Nicovich 10/2/2025 | Approved by

Document type | Document status

Title pivotArmYoke | DWG No.

Rev. | Date of issue | Sheet 1/1

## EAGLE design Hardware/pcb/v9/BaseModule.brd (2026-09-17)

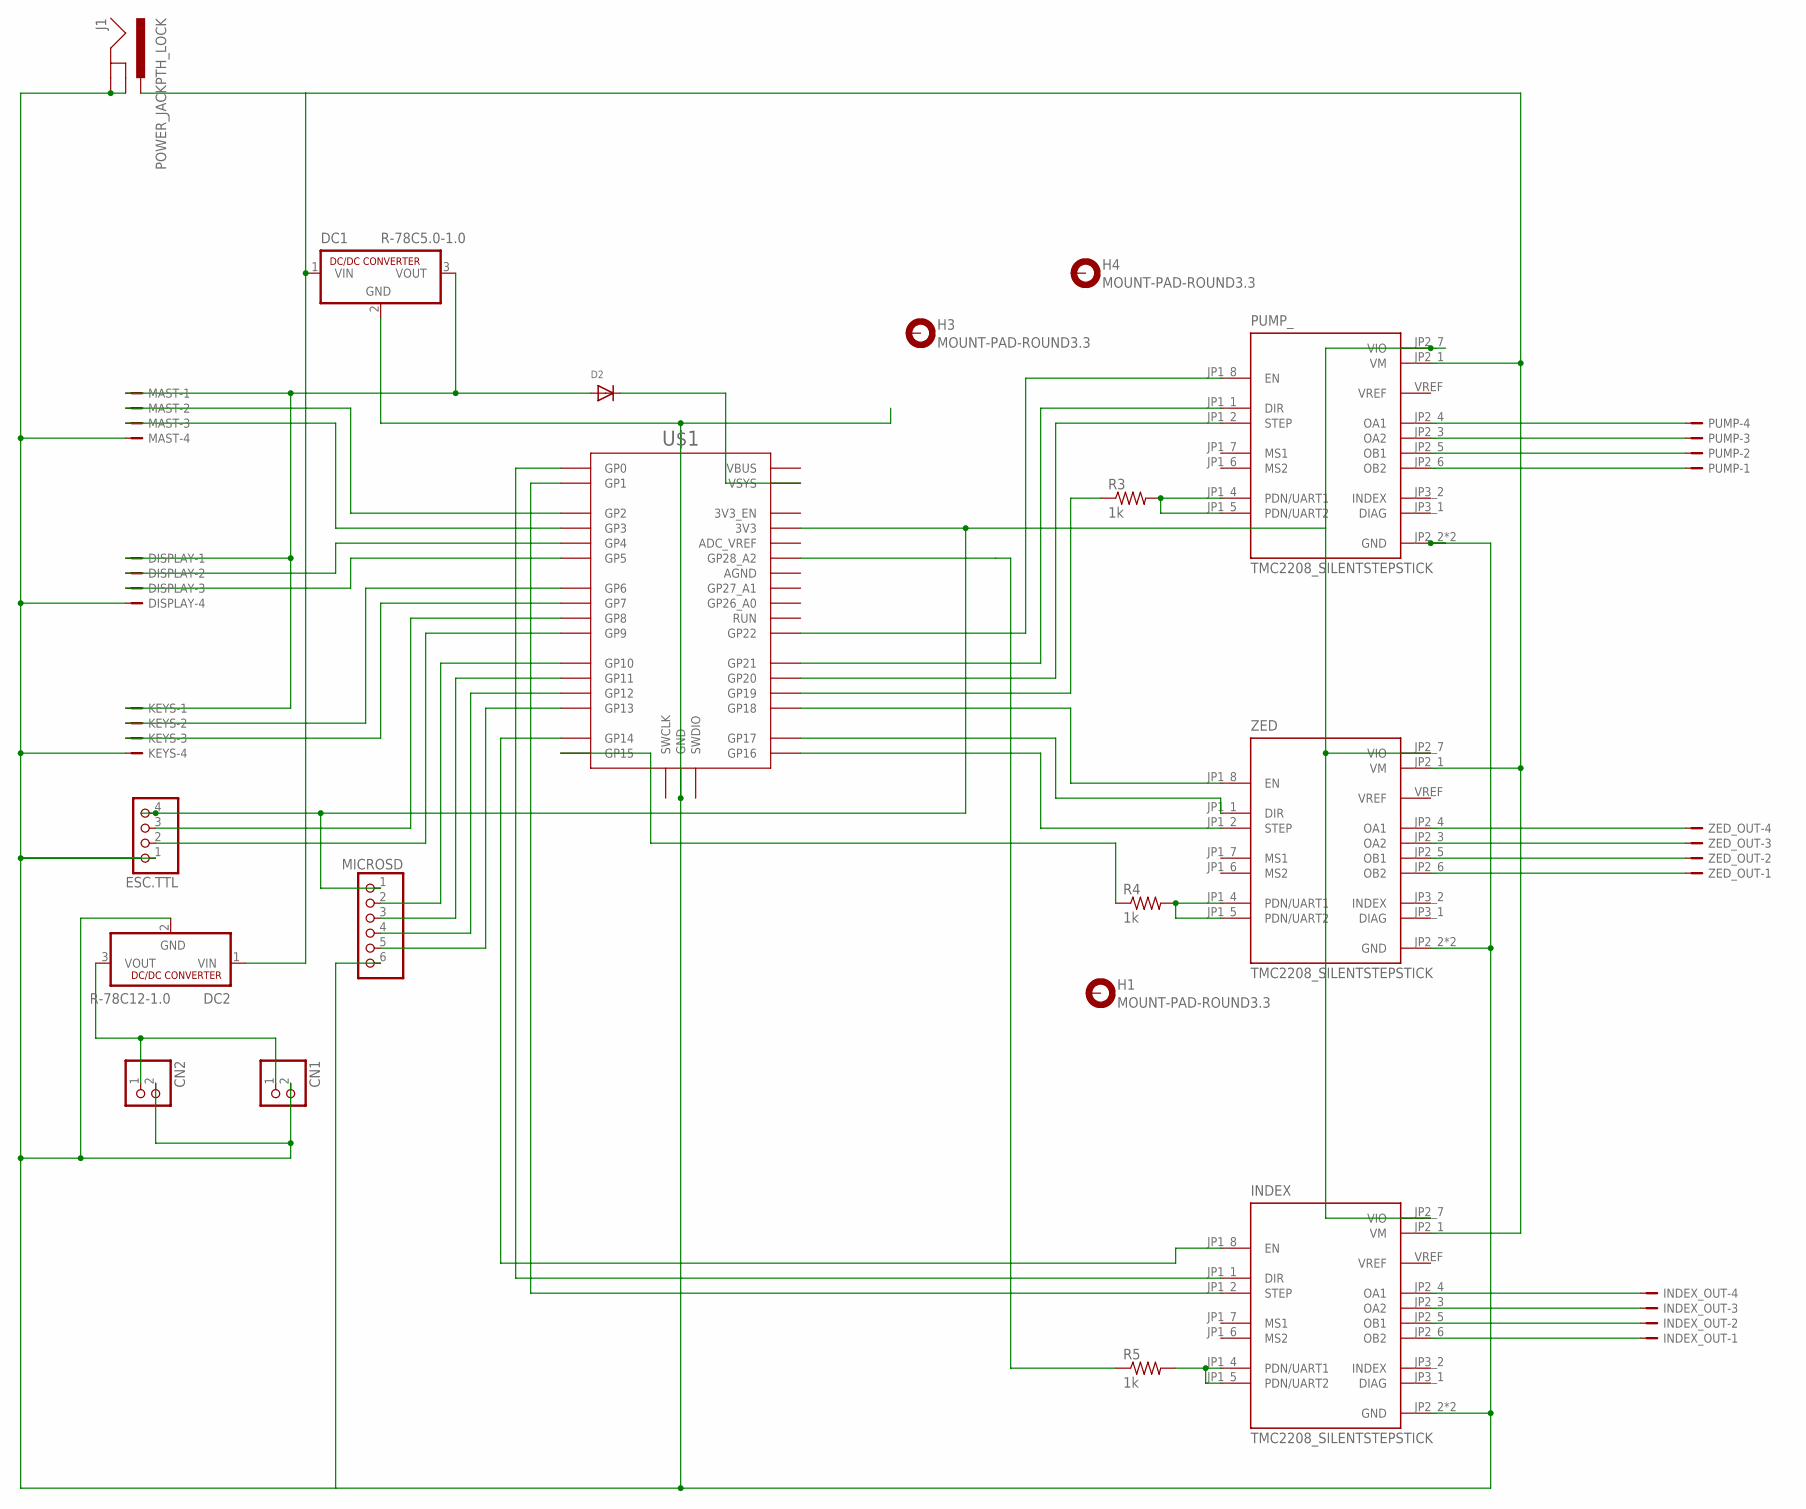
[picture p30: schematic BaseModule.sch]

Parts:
CN1, CN2: JST_2PIN-THM-RA; JST-PH-2-THM-RA
D2: DIODESMA; SMADIODE
DC1: R-78C5.0-1.0; SIP3
DC2: R-78C12-1.0; SIP3
DISPLAY: JST-PH-4_TH-V; B4B-PH-K-S
ESC.TTL: PINHD-1X4; 1X04
H1, H3, H4: MOUNT-PAD-ROUND3.3; 3,3-PAD
INDEX: TMC2208_SILENTSTEPSTICK; MODULE_TMC2208_SILENTSTEPSTICK
INDEX_OUT: JST-PH-4_TH-RA; S4B-PH-KL
J1: POWER_JACKPTH_LOCK; POWER_JACK_PTH_LOCK
KEYS: JST-PH-4_TH-V; B4B-PH-K-S
MAST: JST-PH-4_TH-V; B4B-PH-K-S
MICROSD: PINHD-1X6; 1X06
PUMP: JST-PH-4_TH-RA; S4B-PH-KL
PUMP_: TMC2208_SILENTSTEPSTICK; MODULE_TMC2208_SILENTSTEPSTICK
R3, R4, R5: 1k; R1206
U$1: RPI_PICO-TH; RPI_PICO_TH
ZED: TMC2208_SILENTSTEPSTICK; MODULE_TMC2208_SILENTSTEPSTICK
ZED_OUT: JST-PH-4_TH-RA; S4B-PH-KL

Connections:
5V: D2.C, U$1.VSYS
GND: CN1.2 (1), CN2.2 (1), DC1.2 (GND), DC2.2 (GND), DISPLAY.4, ESC.TTL.1, INDEX.JP2_2 (GND), INDEX.JP2_8 (GND), J1.GND, J1.GNDBREAK, KEYS.4, MAST.4, MICROSD.6, PUMP_.JP2_2 (GND), PUMP_.JP2_8 (GND), U$1.GND@1 (GND), U$1.GND@2 (GND), U$1.GND@3 (GND), U$1.GND@4 (GND), U$1.GND@5 (GND), U$1.GND@6 (GND), U$1.GND@7 (GND), U$1.GND@8 (GND), ZED.JP2_2 (GND), ZED.JP2_8 (GND)
KEYS: KEYS.2, U$1.GP6
unnamed: MICROSD.2, U$1.GP10
unnamed: MICROSD.3, U$1.GP11
unnamed: PUMP_.JP1_4 (PDN/UART1), PUMP_.JP1_5 (PDN/UART2), R3.2
unnamed: R4.2, ZED.JP1_4 (PDN/UART1), ZED.JP1_5 (PDN/UART2)
unnamed: DC1.1 (VIN), DC2.1 (VIN), INDEX.JP2_1 (VM), J1.PWR, PUMP_.JP2_1 (VM), ZED.JP2_1 (VM)
unnamed: U$1.GP18, ZED.JP1_8 (EN)
unnamed: INDEX.JP2_4 (OA1), INDEX_OUT.4
unnamed: MICROSD.4, U$1.GP12
unnamed: ESC.TTL.4, INDEX.JP2_7 (VIO), MICROSD.1, PUMP_.JP2_7 (VIO), U$1.3V3, ZED.JP2_7 (VIO)
unnamed: MICROSD.5, U$1.GP13
unnamed: R4.1, U$1.GP15
unnamed: D2.A, DC1.3 (VOUT), DISPLAY.1, KEYS.1, MAST.1
unnamed: INDEX.JP2_3 (OA2), INDEX_OUT.3
unnamed: ZED.JP2_4 (OA1), ZED_OUT.4
unnamed: ZED.JP2_3 (OA2), ZED_OUT.3
unnamed: ZED.JP2_5 (OB1), ZED_OUT.2
unnamed: ZED.JP2_6 (OB2), ZED_OUT.1
unnamed: PUMP.4, PUMP_.JP2_4 (OA1)
unnamed: PUMP.3, PUMP_.JP2_3 (OA2)
unnamed: PUMP.2, PUMP_.JP2_5 (OB1)
unnamed: PUMP.1, PUMP_.JP2_6 (OB2)
unnamed: U$1.GP17, ZED.JP1_1 (DIR)
unnamed: U$1.GP16, ZED.JP1_2 (STEP)
unnamed: PUMP_.JP1_8 (EN), U$1.GP22
unnamed: PUMP_.JP1_1 (DIR), U$1.GP21
unnamed: PUMP_.JP1_2 (STEP), U$1.GP20
unnamed: R3.1, U$1.GP19
unnamed: MAST.2, U$1.GP2
unnamed: MAST.3, U$1.GP3
unnamed: DISPLAY.2, U$1.GP4
unnamed: DISPLAY.3, U$1.GP5
unnamed: KEYS.3, U$1.GP7
unnamed: ESC.TTL.3, U$1.GP8
unnamed: INDEX.JP2_5 (OB1), INDEX_OUT.2
unnamed: ESC.TTL.2, U$1.GP9
unnamed: CN1.1 (2), CN2.1 (2), DC2.3 (VOUT)
unnamed: INDEX.JP2_6 (OB2), INDEX_OUT.1
unnamed: INDEX.JP1_8 (EN), U$1.GP14
unnamed: R5.1, U$1.GP28_A2
unnamed: INDEX.JP1_4 (PDN/UART1), INDEX.JP1_5 (PDN/UART2), R5.2
unnamed: INDEX.JP1_1 (DIR), U$1.GP0
unnamed: INDEX.JP1_2 (STEP), U$1.GP1

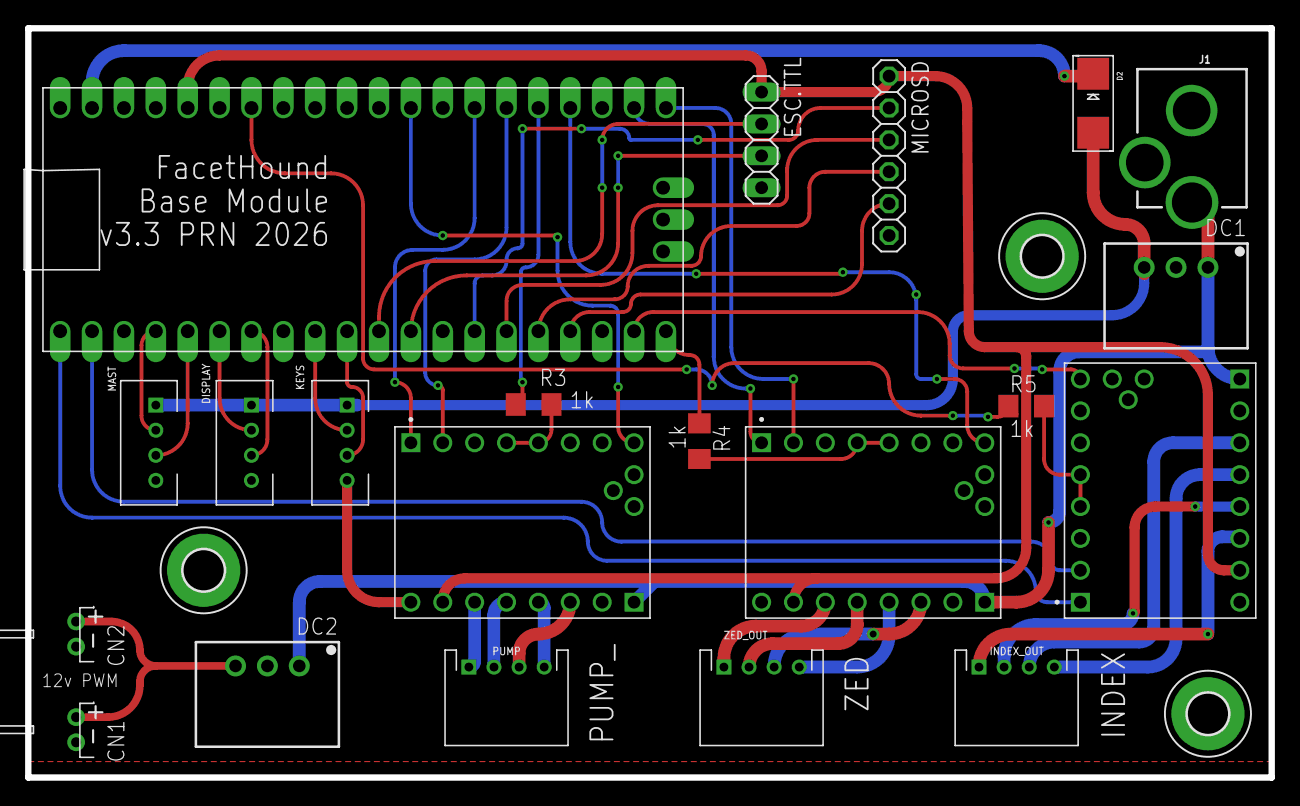
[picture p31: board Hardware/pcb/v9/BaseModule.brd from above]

Board: 2 copper layers, 99.1 x 59.7 mm, 24 parts (0 on the bottom side), 45 nets.

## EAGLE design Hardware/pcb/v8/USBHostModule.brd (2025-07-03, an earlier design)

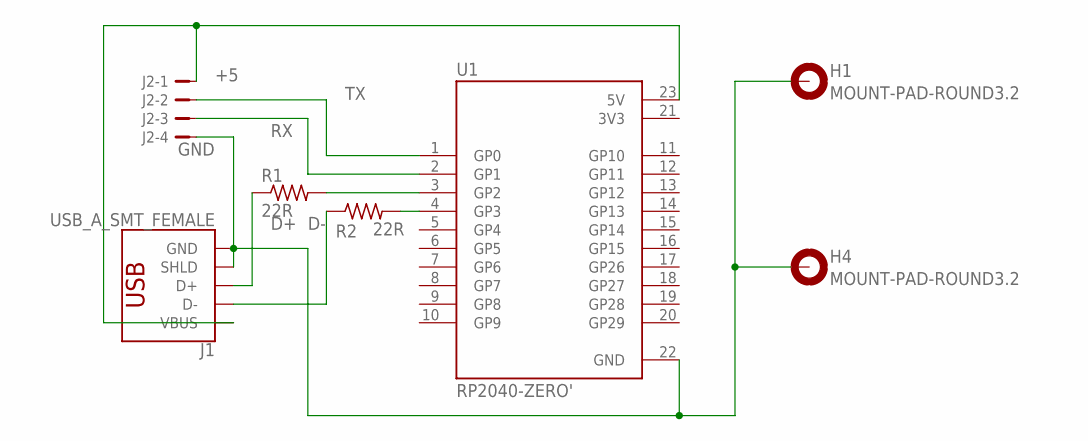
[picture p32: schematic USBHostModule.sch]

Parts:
H1, H4: MOUNT-PAD-ROUND3.2; 3,2-PAD
J1: USB_A_SMT_FEMALE; USB-A-S-SILK-FEMALE
J2: JST-PH-4_TH-RA; S4B-PH-KL
R1, R2: 22R; R1206
U1: RP2040-ZERO'; MODULE_RP2040-ZERO

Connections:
3V3: U1.21 (3V3)
+5: J1.VBUS, J2.1, U1.23 (5V)
D+: J1.D+, R1.1
D-: J1.D-, R2.1
GND: H1.B3,2, H4.B3,2, J1.GND, J1.SHLD1 (SHLD), J1.SHLD2 (SHLD), J2.4, U1.22 (GND)
unnamed: R2.2, U1.4 (GP3)
unnamed: R1.2, U1.3 (GP2)
RX: J2.3, U1.2 (GP1)
TX: J2.2, U1.1 (GP0)

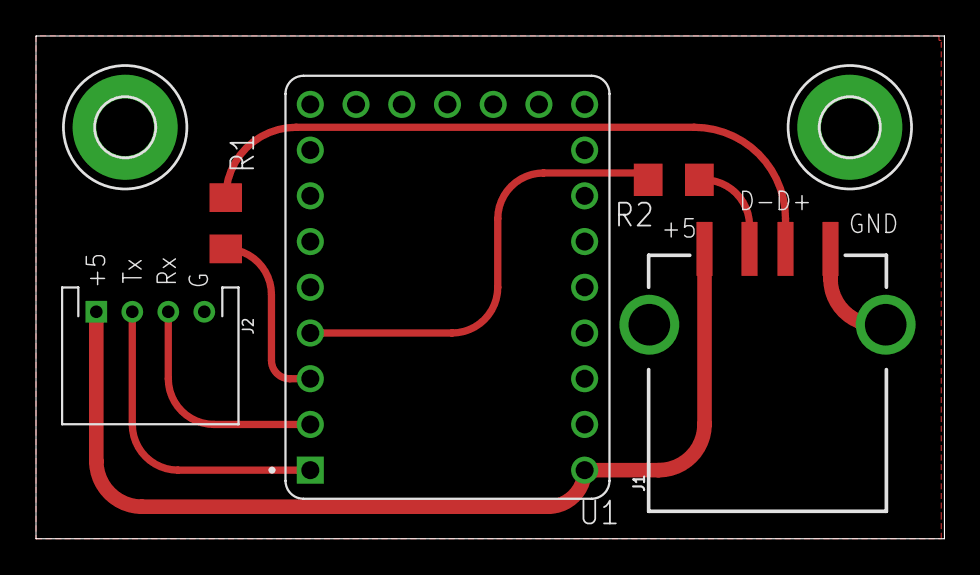
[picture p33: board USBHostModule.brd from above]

Board: 2 copper layers, 50.5 x 27.9 mm, 7 parts (0 on the bottom side), 8 nets.

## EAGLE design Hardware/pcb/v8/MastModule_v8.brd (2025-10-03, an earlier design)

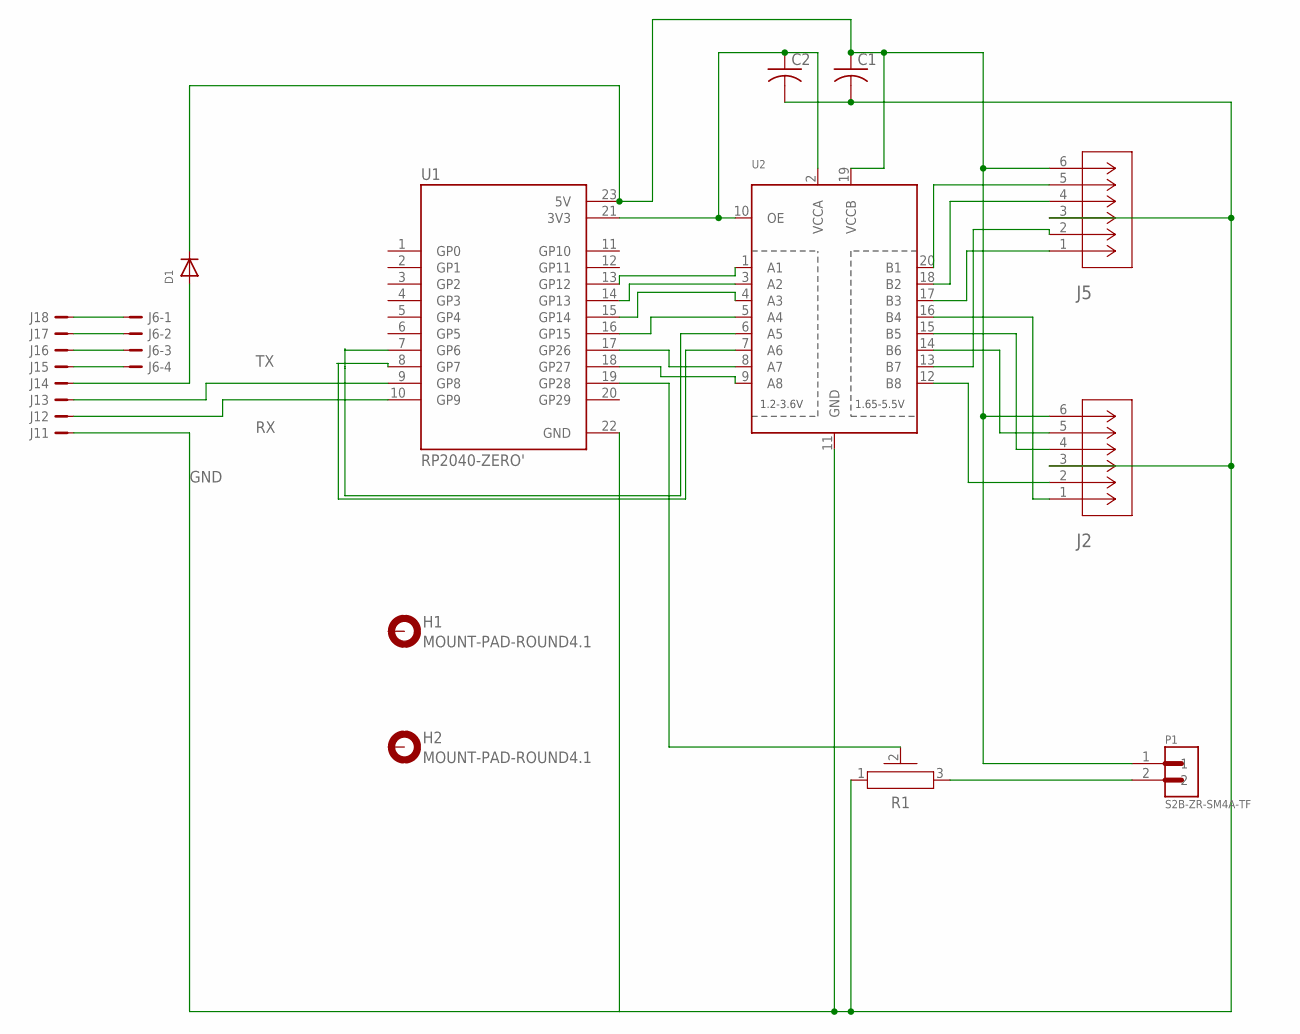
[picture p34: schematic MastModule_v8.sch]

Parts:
C1, C2: C-USC1210; C1210
D1: DIODESMA; SMADIODE
H1, H2: MOUNT-PAD-ROUND4.1; 4,1-PAD
J1: B8B-PH-K-S
J2, J5: 2132260630CONN_2132260000-SD_06_MOL; CONN_2132260000-SD_06_MOL
J6: JST-PH-4_TH-RA; S4B-PH-KL
P1: S2B-ZR-SM4A-TF; JST_S2B-ZR-SM4A-TF
R1: PV36X
U1: RP2040-ZERO'; MODULE_RP2040-ZERO
U2: TXB0108PWR; TSSOP20

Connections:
3V3: C2.1, U1.21 (3V3), U2.2 (VCCA), U2.10 (OE)
5V: C1.1, D1.C, J2.6, J5.6, P1.1, U1.23 (5V), U2.19 (VCCB)
GND: C1.2, C2.2, J1.1, J2.3, J5.3, R1.1, U1.22 (GND), U2.11 (GND)
unnamed: J1.8, J6.1
unnamed: J1.7, J6.2
unnamed: J1.6, J6.3
unnamed: J1.5, J6.4
unnamed: D1.A, J1.4
unnamed: U1.17 (GP26), U2.8 (A7)
unnamed: J5.5, U2.20 (B1)
unnamed: J5.4, U2.18 (B2)
unnamed: R1.2, U1.19 (GP28)
unnamed: P1.2, R1.3
unnamed: J5.1, U2.17 (B3)
unnamed: J2.1, U2.16 (B4)
unnamed: J2.4, U2.15 (B5)
unnamed: J2.5, U2.14 (B6)
unnamed: U1.18 (GP27), U2.9 (A8)
unnamed: J5.2, U2.13 (B7)
unnamed: J2.2, U2.12 (B8)
unnamed: U1.8 (GP7), U2.7 (A6)
unnamed: U1.7 (GP6), U2.6 (A5)
unnamed: U1.13 (GP12), U2.1 (A1)
unnamed: U1.14 (GP13), U2.3 (A2)
unnamed: U1.15 (GP14), U2.4 (A3)
unnamed: U1.16 (GP15), U2.5 (A4)
RX: J1.2, U1.10 (GP9)
TX: J1.3, U1.9 (GP8)

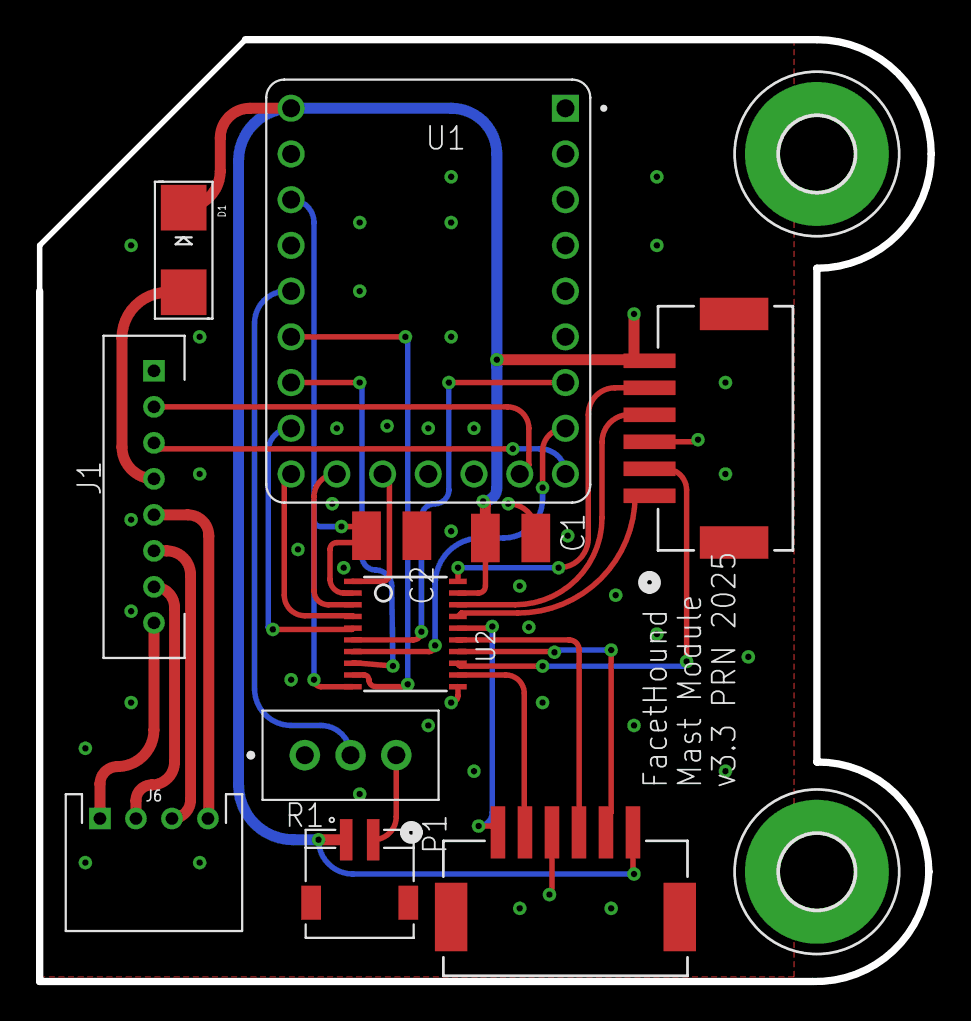
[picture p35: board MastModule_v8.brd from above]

Board: 2 copper layers, 49.5 x 52.3 mm, 13 parts (0 on the bottom side), 28 nets.

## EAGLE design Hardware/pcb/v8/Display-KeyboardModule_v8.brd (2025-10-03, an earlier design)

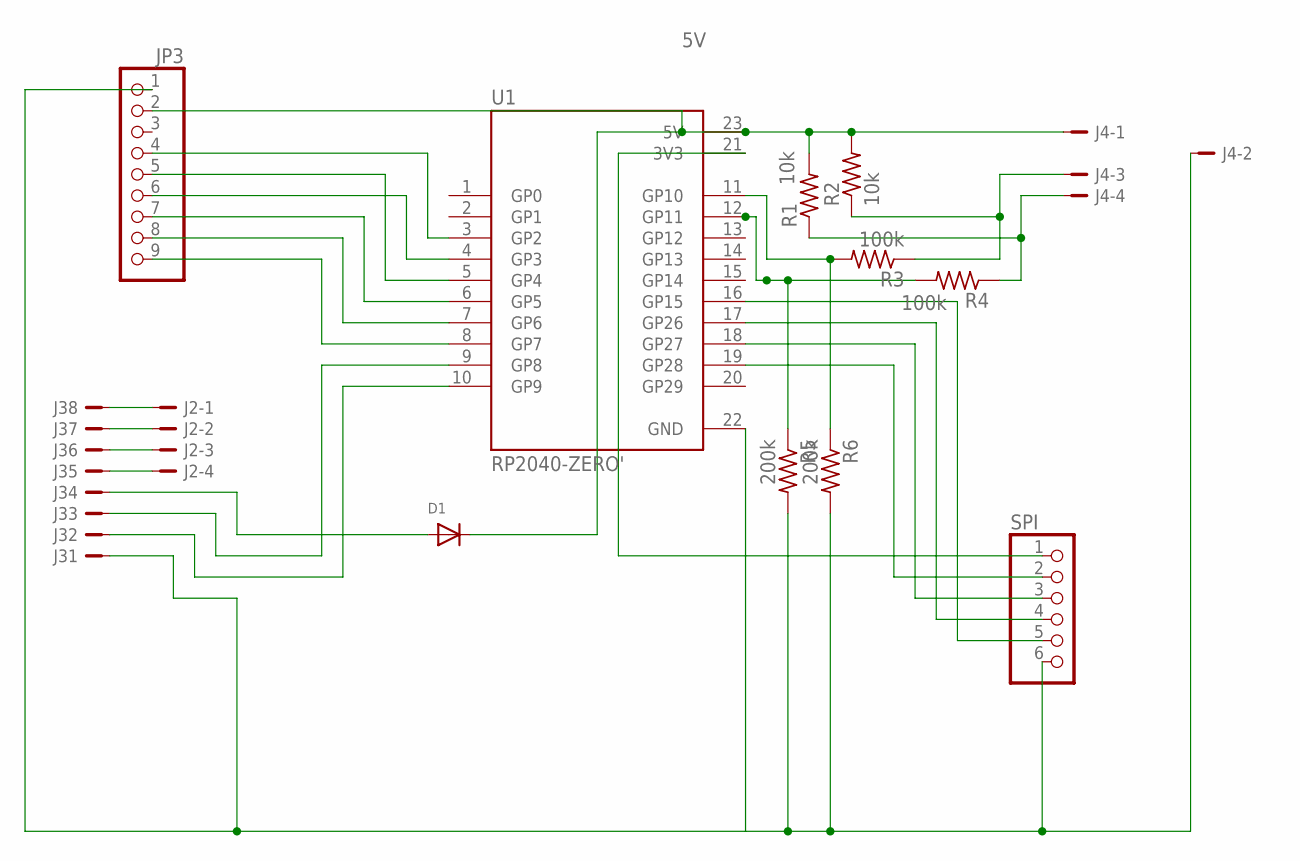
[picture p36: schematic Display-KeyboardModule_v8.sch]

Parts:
D1: DIODESMA; SMADIODE
J2, J4: JST-PH-4_TH-RA; S4B-PH-KL
J3: B8B-PH-K-S
JP3: PINHD-1X9; 1X09-BIG
R1, R2: 10k; R1206
R3, R4: 100k; R1206
R5, R6: 200k; R1206
SPI: PINHD-1X6; 1X06
U1: RP2040-ZERO'; MODULE_RP2040-ZERO

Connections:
5V: D1.C, J4.1, JP3.2, R1.2, R2.2, U1.23 (5V)
GND: J3.1, J4.2, JP3.1, R5.2, R6.2, SPI.6, U1.22 (GND)
unnamed: D1.A, J3.4
unnamed: J2.1, J3.8
unnamed: JP3.4, U1.3 (GP2)
unnamed: J3.3, U1.9 (GP8)
unnamed: J3.2, U1.10 (GP9)
unnamed: JP3.6, U1.4 (GP3)
unnamed: JP3.5, U1.5 (GP4)
unnamed: JP3.7, U1.6 (GP5)
unnamed: JP3.8, U1.7 (GP6)
unnamed: JP3.9, U1.8 (GP7)
unnamed: SPI.2, U1.19 (GP28)
unnamed: J4.3, R2.1, R3.1
unnamed: J2.2, J3.7
unnamed: J2.3, J3.6
unnamed: J2.4, J3.5
unnamed: SPI.3, U1.18 (GP27)
unnamed: J4.4, R1.1, R4.1
unnamed: SPI.4, U1.17 (GP26)
unnamed: R3.2, R6.1, U1.11 (GP10)
unnamed: SPI.5, U1.16 (GP15)
unnamed: SPI.1, U1.21 (3V3)
unnamed: R4.2, R5.1, U1.12 (GP11)

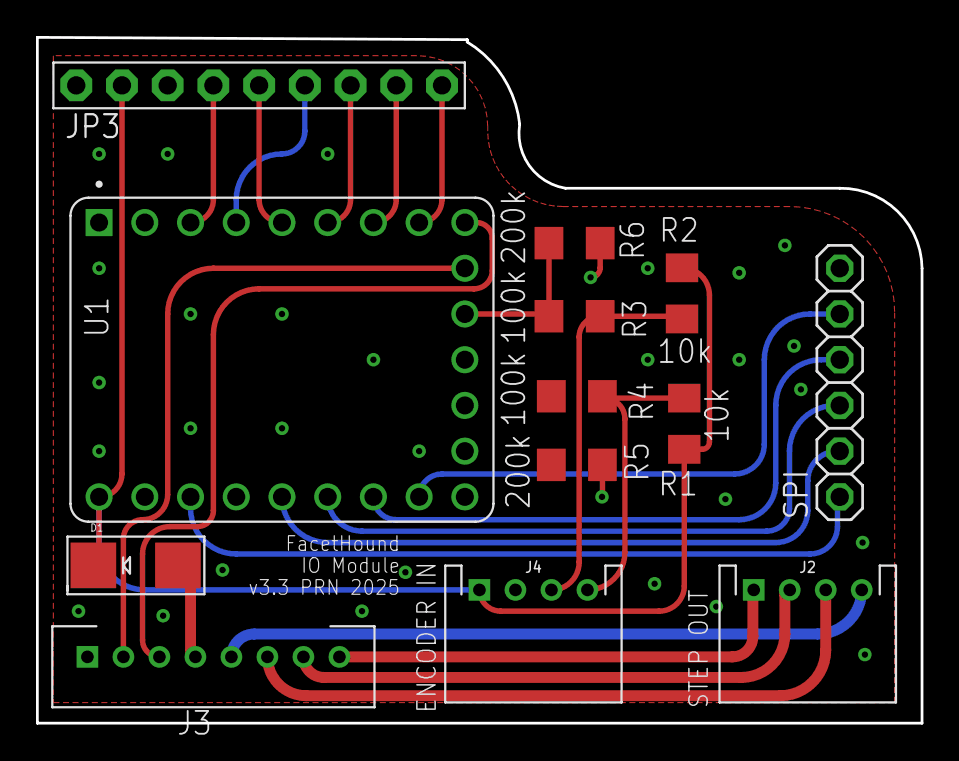
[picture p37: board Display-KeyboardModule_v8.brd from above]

Board: 2 copper layers, 49.1 x 38.1 mm, 13 parts (0 on the bottom side), 24 nets.

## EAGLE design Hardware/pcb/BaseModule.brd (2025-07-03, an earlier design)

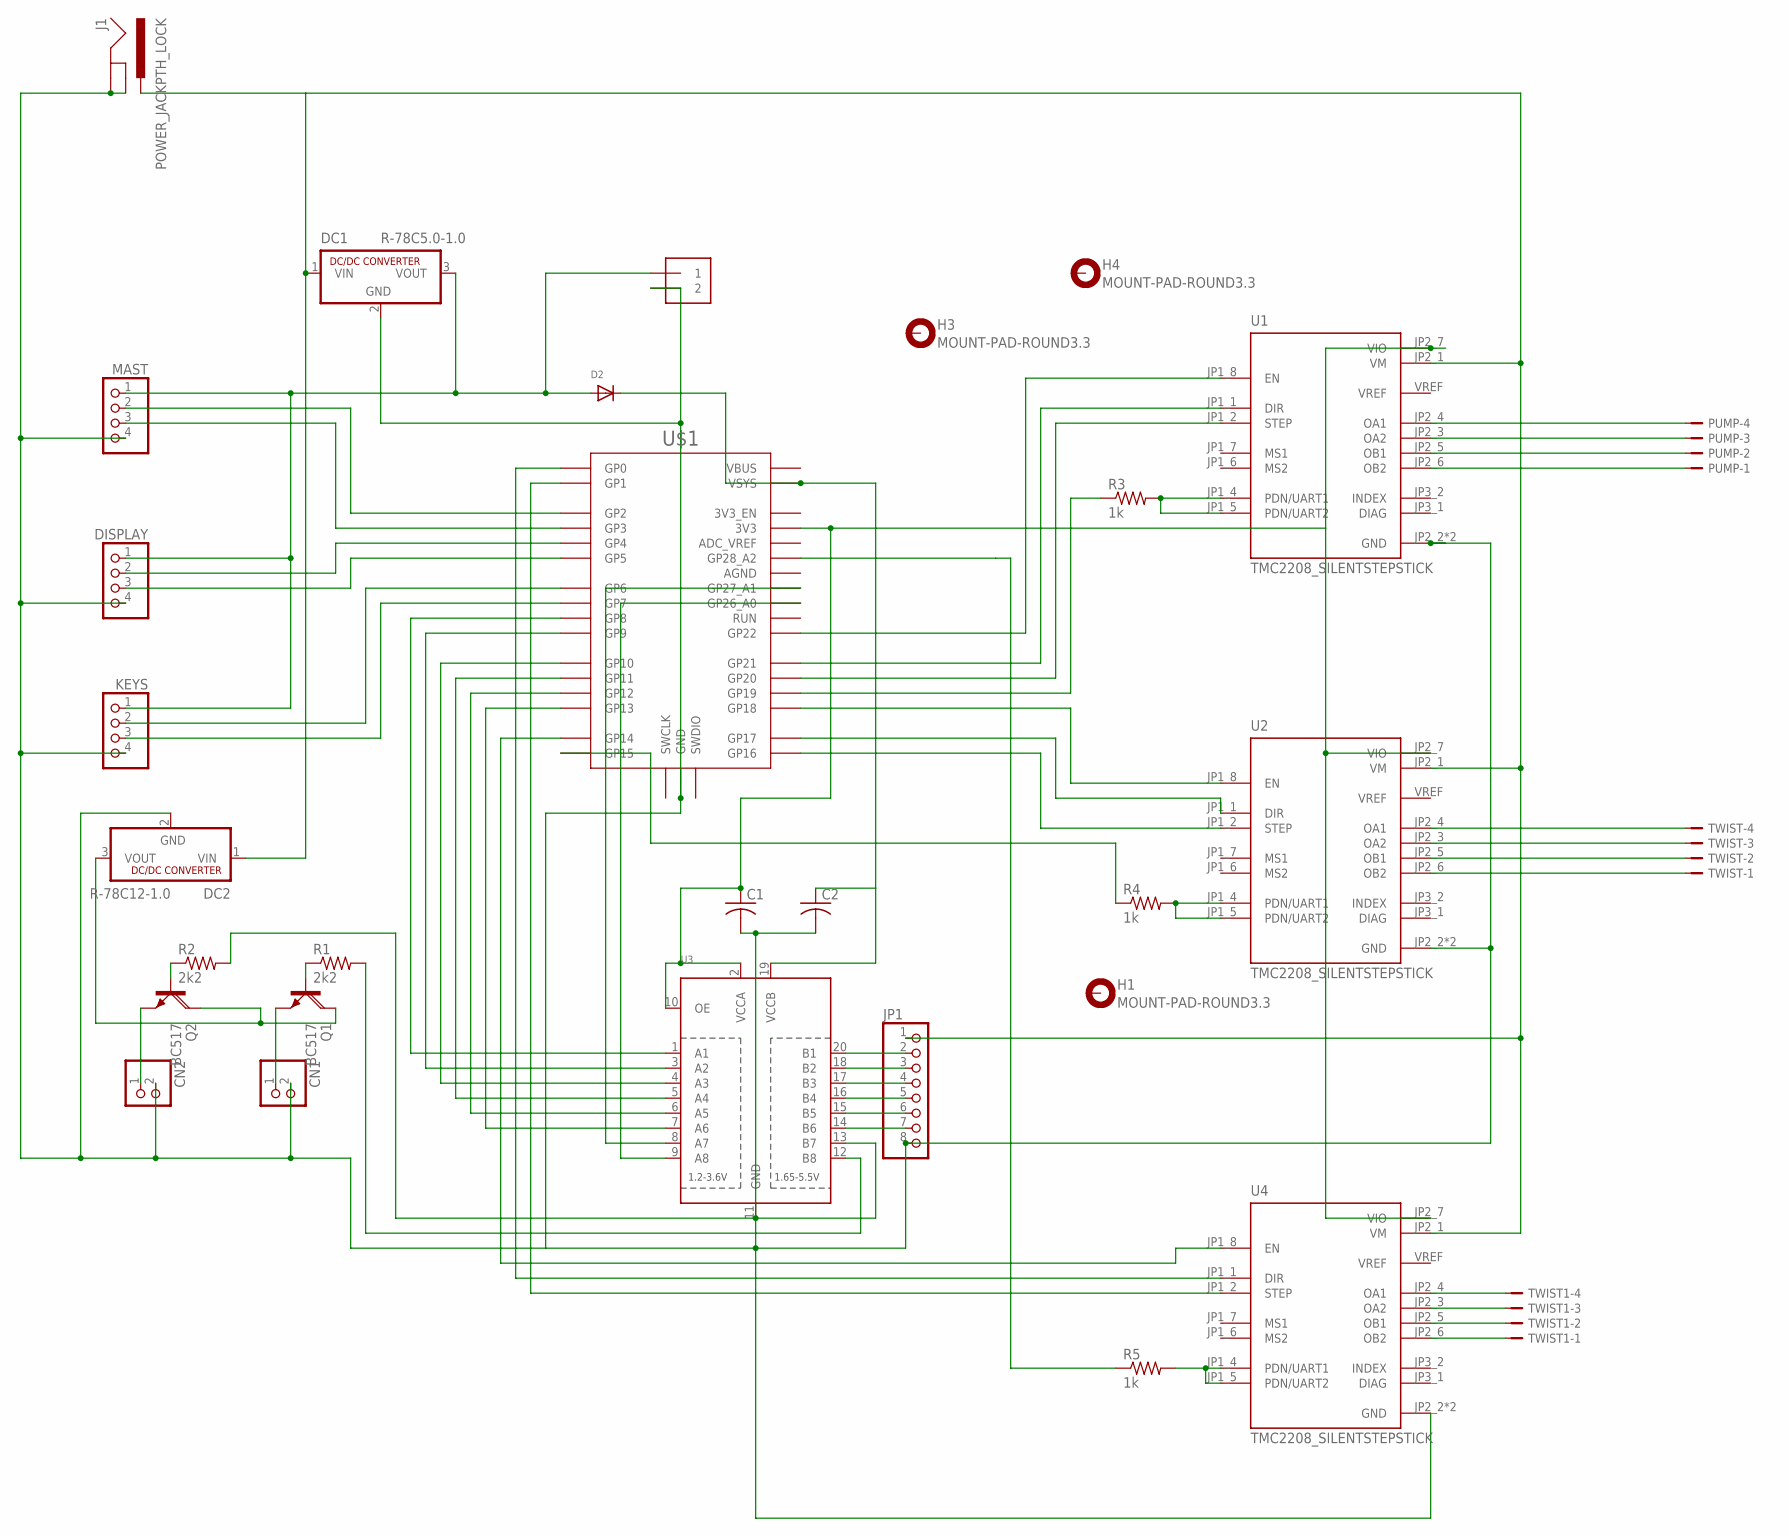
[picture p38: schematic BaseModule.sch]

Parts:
C1, C2: C-USC1206; C1206
CN1, CN2: JST_2PIN-THM-RA; JST-PH-2-THM-RA
D2: DIODESMA; SMADIODE
DC1: R-78C5.0-1.0; SIP3
DC2: R-78C12-1.0; SIP3
DISPLAY: PINHD-1X4; 1X04
H1, H3, H4: MOUNT-PAD-ROUND3.3; 3,3-PAD
J1: POWER_JACKPTH_LOCK; POWER_JACK_PTH_LOCK
J2: 1X2-3.5MM
JP1: PINHD-1X8-3.5MM; 1X08-3.5MM
KEYS: PINHD-1X4; 1X04
MAST: PINHD-1X4; 1X04
PUMP: JST-PH-4_TH-RA; S4B-PH-KL
Q1, Q2: BC517; SOT54A
R1, R2: 2k2; R1206
R3, R4, R5: 1k; R1206
TWIST, TWIST1: JST-PH-4_TH-RA; S4B-PH-KL
U1, U2, U4: TMC2208_SILENTSTEPSTICK; MODULE_TMC2208_SILENTSTEPSTICK
U3: TXB0108PWR; TSSOP20
U$1: RPI_PICO-TH; RPI_PICO_TH

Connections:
GND: C1.2, C2.2, CN1.2 (1), CN2.2 (1), DC1.2 (GND), DC2.2 (GND), DISPLAY.4, J1.GND, J1.GNDBREAK, J2.2, JP1.8, KEYS.4, MAST.4, U1.JP2_2 (GND), U1.JP2_8 (GND), U2.JP2_2 (GND), U2.JP2_8 (GND), U3.11 (GND), U4.JP2_2 (GND), U4.JP2_8 (GND), U$1.GND@1 (GND), U$1.GND@2 (GND), U$1.GND@3 (GND), U$1.GND@4 (GND), U$1.GND@5 (GND), U$1.GND@6 (GND), U$1.GND@7 (GND), U$1.GND@8 (GND)
unnamed: Q1.B, R1.1
unnamed: Q2.B, R2.1
unnamed: R3.2, U1.JP1_4 (PDN/UART1), U1.JP1_5 (PDN/UART2)
unnamed: R4.2, U2.JP1_4 (PDN/UART1), U2.JP1_5 (PDN/UART2)
unnamed: DC1.1 (VIN), DC2.1 (VIN), J1.PWR, JP1.1, U1.JP2_1 (VM), U2.JP2_1 (VM), U4.JP2_1 (VM)
unnamed: U2.JP1_8 (EN), U$1.GP18
unnamed: TWIST1.4, U4.JP2_4 (OA1)
unnamed: C2.1, D2.C, U3.19 (VCCB), U$1.VSYS
unnamed: U3.7 (A6), U$1.GP13
unnamed: CN2.1 (2), Q2.E
unnamed: JP1.2, U3.20 (B1)
unnamed: R4.1, U$1.GP15
unnamed: D2.A, DC1.3 (VOUT), DISPLAY.1, J2.1, KEYS.1, MAST.1
unnamed: TWIST1.3, U4.JP2_3 (OA2)
unnamed: TWIST.4, U2.JP2_4 (OA1)
unnamed: TWIST.3, U2.JP2_3 (OA2)
unnamed: TWIST.2, U2.JP2_5 (OB1)
unnamed: TWIST.1, U2.JP2_6 (OB2)
unnamed: PUMP.4, U1.JP2_4 (OA1)
unnamed: PUMP.3, U1.JP2_3 (OA2)
unnamed: PUMP.2, U1.JP2_5 (OB1)
unnamed: PUMP.1, U1.JP2_6 (OB2)
unnamed: U2.JP1_1 (DIR), U$1.GP17
unnamed: U2.JP1_2 (STEP), U$1.GP16
unnamed: JP1.3, U3.18 (B2)
unnamed: U1.JP1_8 (EN), U$1.GP22
unnamed: U1.JP1_1 (DIR), U$1.GP21
unnamed: U1.JP1_2 (STEP), U$1.GP20
unnamed: R3.1, U$1.GP19
unnamed: MAST.2, U$1.GP2
unnamed: MAST.3, U$1.GP3
unnamed: DISPLAY.2, U$1.GP4
unnamed: DISPLAY.3, U$1.GP5
unnamed: KEYS.2, U$1.GP6
unnamed: KEYS.3, U$1.GP7
unnamed: CN1.1 (2), Q1.E
unnamed: JP1.4, U3.17 (B3)
unnamed: JP1.5, U3.16 (B4)
unnamed: JP1.6, U3.15 (B5)
unnamed: JP1.7, U3.14 (B6)
unnamed: U3.1 (A1), U$1.GP8
unnamed: TWIST1.2, U4.JP2_5 (OB1)
unnamed: C1.1, U1.JP2_7 (VIO), U2.JP2_7 (VIO), U3.2 (VCCA), U3.10 (OE), U4.JP2_7 (VIO), U$1.3V3
unnamed: R2.2, U3.13 (B7)
unnamed: R1.2, U3.12 (B8)
unnamed: U3.3 (A2), U$1.GP9
unnamed: U3.4 (A3), U$1.GP10
unnamed: U3.5 (A4), U$1.GP11
unnamed: U3.6 (A5), U$1.GP12
unnamed: DC2.3 (VOUT), Q1.C, Q2.C
unnamed: U3.8 (A7), U$1.GP27_A1
unnamed: U3.9 (A8), U$1.GP26_A0
unnamed: TWIST1.1, U4.JP2_6 (OB2)
unnamed: U4.JP1_8 (EN), U$1.GP14
unnamed: R5.1, U$1.GP28_A2
unnamed: R5.2, U4.JP1_4 (PDN/UART1), U4.JP1_5 (PDN/UART2)
unnamed: U4.JP1_1 (DIR), U$1.GP0
unnamed: U4.JP1_2 (STEP), U$1.GP1

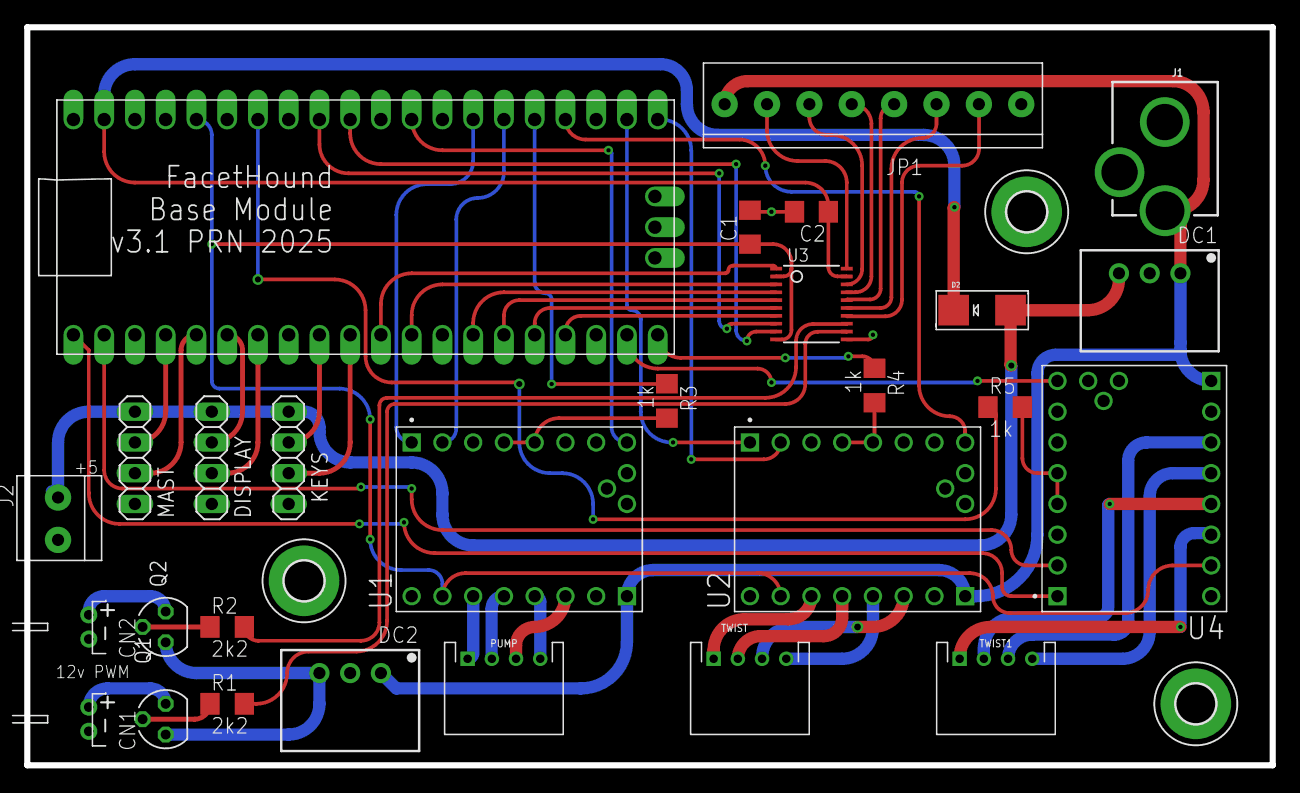
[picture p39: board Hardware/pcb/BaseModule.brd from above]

Board: 2 copper layers, 102.9 x 61.0 mm, 31 parts (0 on the bottom side), 59 nets.

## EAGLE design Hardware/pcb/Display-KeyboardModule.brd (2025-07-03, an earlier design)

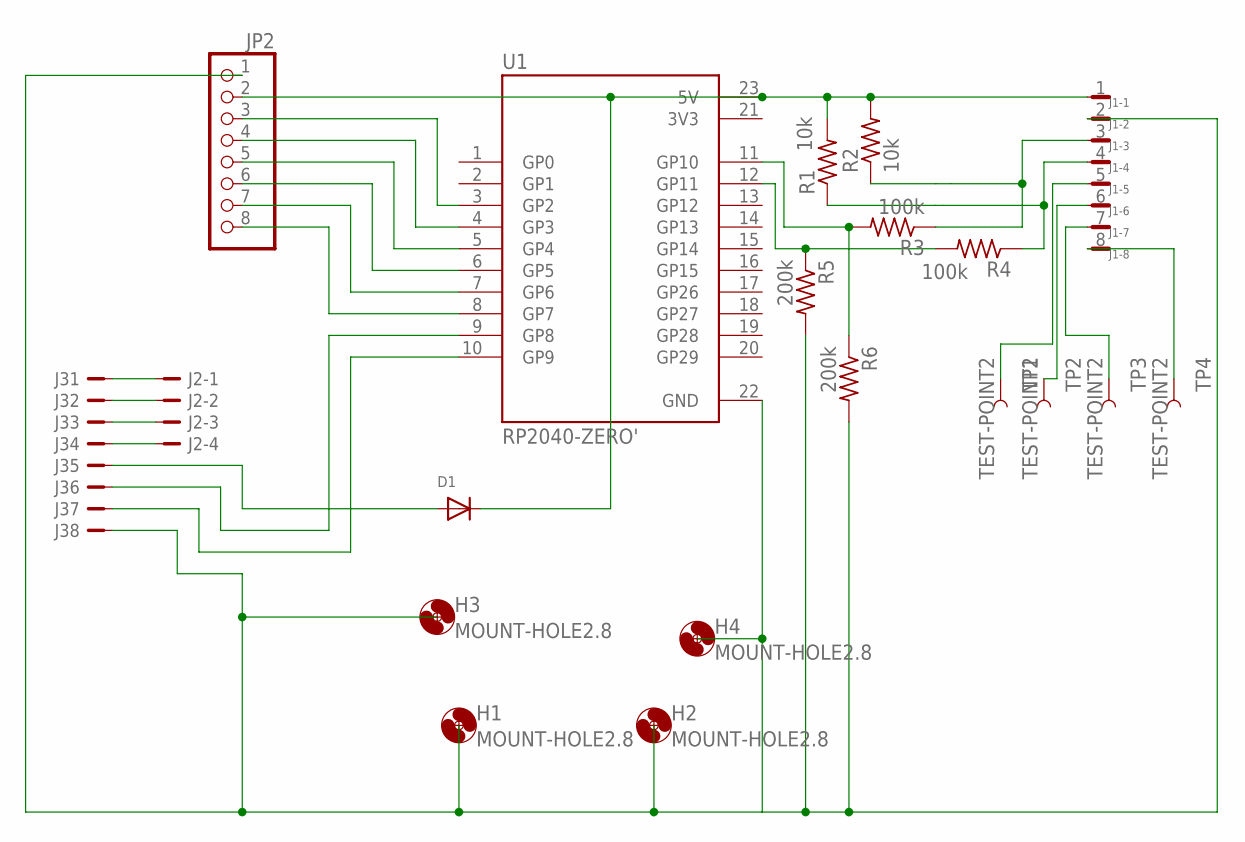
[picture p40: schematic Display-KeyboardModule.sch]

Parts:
D1: DIODESMA; SMADIODE
H1, H2, H3, H4: MOUNT-HOLE2.8; 2,8
J1: JST-SH-8_RA; SM08B-SRSS-TB
J2: JST-PH-4_TH-RA; S4B-PH-KL
J3: B8B-PH-K-S
JP2: PINHD-1X8/90; 1X08/90
R1, R2: 10k; R1206
R3, R4: 100k; R1206
R5, R6: 200k; R1206
TP1, TP2, TP3, TP4: TEST-POINT2; PAD.02X.02
U1: RP2040-ZERO'; MODULE_RP2040-ZERO

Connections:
3V3: U1.21 (3V3)
GND: J1.2, J3.8, JP2.1, R5.2, R6.2, U1.22 (GND)
unnamed: D1.A, J3.5
unnamed: J2.1, J3.1
unnamed: JP2.3, U1.3 (GP2)
unnamed: J3.6, U1.9 (GP8)
unnamed: J3.7, U1.10 (GP9)
unnamed: JP2.4, U1.4 (GP3)
unnamed: JP2.5, U1.5 (GP4)
unnamed: JP2.6, U1.6 (GP5)
unnamed: JP2.7, U1.7 (GP6)
unnamed: JP2.8, U1.8 (GP7)
unnamed: D1.C, J1.1, JP2.2, R1.2, R2.2, U1.23 (5V)
unnamed: J1.3, R2.1, R3.1
unnamed: J2.2, J3.2
unnamed: J1.8, TP4.1
unnamed: J1.7, TP3.1
unnamed: J1.6, TP2.1
unnamed: J1.4, R1.1, R4.1
unnamed: J1.5, TP1.1
unnamed: R4.2, R5.1, U1.12 (GP11)
unnamed: R3.2, R6.1, U1.11 (GP10)
unnamed: J2.3, J3.3
unnamed: J2.4, J3.4

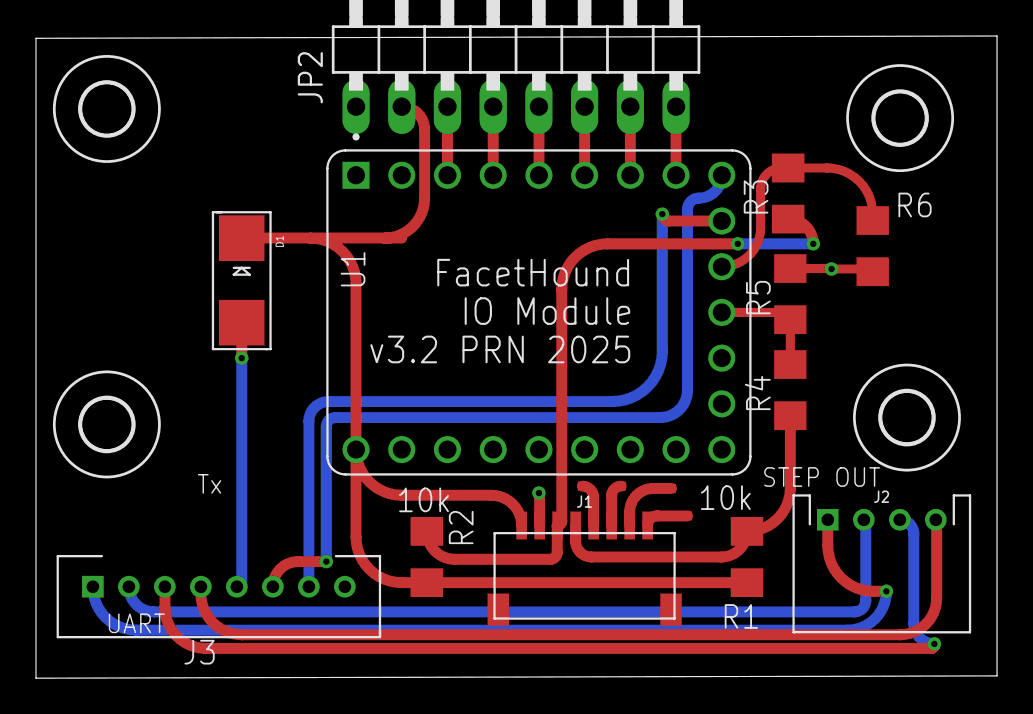
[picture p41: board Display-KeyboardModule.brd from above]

Board: 2 copper layers, 53.4 x 35.7 mm, 20 parts (0 on the bottom side), 23 nets.

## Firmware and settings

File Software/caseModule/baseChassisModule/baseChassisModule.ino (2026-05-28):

#include <TMC2209.h>
#include "FreqCountRP2.h"
#include "buttonFunctions.h"
#include <AccelStepper.h>
#include <LinkedList.h>

#include "CRC16.h"
#include "CRC.h"

#include <LittleFS.h>
#include <VFS.h>


#define KEYS_TX_PIN 7
#define KEYS_RX_PIN 6

#define DISP_TX_PIN 5
#define DISP_RX_PIN 4

#define MAST_TX_PIN 3
#define MAST_RX_PIN 2

#define ACK 1
#define NAK 0

#define motorALMpin 8
#define motorPGpin 9
#define motorSVpin 10
#define motorBKpin 11
#define motorENpin 12
#define motorFRpin 13

#define FAN_PIN 27
#define LAMP_PIN 26


#define TWIST_EN_PIN 14
#define TWIST_TX_PIN 28
#define TWIST_DIR_PIN 0
#define TWIST_STEP_PIN 1

#define ZED_EN_PIN 18
#define ZED_TX_PIN 15
#define ZED_DIR_PIN 17
#define ZED_STEP_PIN 16

#define PUMP_EN_PIN 22
#define PUMP_TX_PIN 19
#define PUMP_DIR_PIN 21
#define PUMP_STEP_PIN 20


#define RPM_LIMIT_HIGH 200
#define RPM_LIMIT_LOW 0
#define motorMaxRPM 3500
#define motorNPoles 3

#define DISP_IN 0
#define MAST_IN 1

#define doubleClickTime  100 // milliseconds

#define indexDirection true // True for + to CW (ULTRATECH), false for + to CCW (FACETRON)

SerialPIO keysSerial(KEYS_TX_PIN, KEYS_RX_PIN);
SerialPIO dispSerial(DISP_TX_PIN, DISP_RX_PIN);
SerialPIO mastSerial(MAST_TX_PIN, MAST_RX_PIN);

#define TMC2209_SERIAL_BAUD_RATE 19200

SerialPIO twistSerial(TWIST_TX_PIN, SerialPIO::NOPIN);
SerialPIO pumpSerial(PUMP_TX_PIN, SerialPIO::NOPIN);
SerialPIO zedSerial(ZED_TX_PIN, SerialPIO::NOPIN);

// Instantiate TMC2209 class objects
TMC2209 twistDriver;
TMC2209 zedDriver;
TMC2209 pumpDriver;

// current values may need to be reduced to prevent overheating depending on
// specific motor and power supply voltage
uint32_t TWIST_RMS_CURRENT = 1000;
int32_t TWIST_RUN_VELOCITY = 2000;
bool TWIST_DIR = false;
uint16_t TWIST_MICROSTEPS = 256;
float TWIST_MAX_SPEED = 200000.0;
float TWIST_ACCELERATION = 100000.0;
float TWIST_STEP_SPEED = 2500;

uint32_t ZED_RMS_CURRENT = 800;
int32_t ZED_RUN_VELOCITY = 100000;
bool ZED_DIR = false;
uint16_t ZED_MICROSTEPS = 128;
float ZED_MAX_SPEED = 400000.0;
float ZED_ACCELLERATION = 100000.0;
float ZED_STEP_SPEED = 10000;

uint32_t PUMP_RMS_CURRENT = 1100;
int32_t PUMP_RUN_VELOCITY = 1000;
bool PUMP_DIR = true;
uint16_t PUMP_MICROSTEPS = 4;



//FastAccelStepperEngine engine = FastAccelStepperEngine();
//FastAccelStepper* stepper = NULL;

AccelStepper twistDirStep(AccelStepper::DRIVER, TWIST_STEP_PIN, TWIST_DIR_PIN);
AccelStepper zedDirStep(AccelStepper::DRIVER, ZED_STEP_PIN, ZED_DIR_PIN);

uint8_t keyString[] = { 0, 0, 0, 0, 0, 0, 0 };
long k = 0;

bool lastValWasSep = true;
uint8_t lastVal = 0;

long lastQueryTime = 0;
long frameCycleTime = 20;  // milliseconds

uint32_t TILT_MOTOR_STEPS_PER_ROT = 200;
uint32_t TILT_STEPS_PER_ROT = TILT_MOTOR_STEPS_PER_ROT*TWIST_MICROSTEPS;

float supportedIndexes[] = {1.0, 2.0, 2*PI, 32, 40, 48, 60, 64, 72, 77, 80, 81, 88, 91, 96, 98, 99, 100, 102, 104, 110, 120, 128, 144, 192, 256, 360, 400};
uint8_t indexIndex = 14;
uint8_t nIndexes = 28;

float wheelIndex = 64.0;
float indexEncoderSteps = 65535.0;
bool updateTiltAngle = true;
float tiltAngle = 0;
float targetTilt_float = 0.0;
uint32_t targetTilt = 0;
uint32_t tiltEncRaw = 0;
float tiltConversion = 0;
float tiltStepsPerIndexUnit = 0;
float tiltMult[] = { 1.0, 0.1, 0.005 };
int tiltIdx = 1;
bool tiltLock = true;
bool tiltDir = false;
float tiltZero = 1;
bool spinServoIdx = false;
float servoRelease = 120.0; // degrees
float servoCapture = 105.0; // degrees
bool cheatMode = false;
float tiltRecall = 0;
bool firstCrossServoThreshold = true;
float twistErrorProportionalTerm = 0.2;
float degreesAndDirection = 0;
float positionErrorTolerance = 0.013;
int nLocks = 0;

// float tiltAngleMemory[] = {0, 12, 24, 36, 48, 60, 72, 84}; // 96 wheel
float tiltAngleMemory[] = {0, 6, 12, 18, 24, 30, 36, 42, 48, 54, 60, 66, 72, 78, 84, 90}; // 96 wheel, porto
// float tiltAngleMemory[] = {0, 8, 16, 24, 32, 40, 48, 64, 72, 80, 88, 96}; // 104 wheel
//float tiltAngleMemory[] = {3, 18, 25, 41, 47, 63, 69, 85, 91, 107}; // 110 wheel, Astro
// float tiltAngleMemory[] = {0, 16, 32, 48, 64}; // 80 wheel
LinkedList<float> markPoints = LinkedList<float>();



int8_t tiltMemIdx = 1;
uint8_t tiltMemNPts = sizeof(tiltAngleMemory) / sizeof(tiltAngleMemory[0]);

bool updateTipAngle = true;
float tipAngle = 0;
uint32_t tipEncRaw = 0;
float tipConversion = 360.0 / 131072.0;
long tipZero = 47850;

bool updateZValue = true;


uint32_t ZED_MOTOR_STEPS_PER_ROT = 100;
uint32_t ZED_STEPS_PER_ROT = ZED_MOTOR_STEPS_PER_ROT*ZED_MICROSTEPS;

bool zedDir = false;
float zValue = 0;
int32_t zEncSteps = 0;
float zedIndexInitsPerWheelTurn = 5e-3;
float zedGearRatio = 4;
float zedEncoderOversample = 4;
float zConversionFactor = zedIndexInitsPerWheelTurn / (zedGearRatio*zedEncoderOversample);
float zedStepsPerIndexUnit = ZED_MOTOR_STEPS_PER_ROT / zedIndexInitsPerWheelTurn;
int zMult[] = {int(zedStepsPerIndexUnit), int(0.05*zedStepsPerIndexUnit), int(0.0005*zedStepsPerIndexUnit)};
int zIdx = 0;
bool zLock = false;

bool updateRPMValue = true;
long RPMValue = 0;
int8_t RPM_dir = 1;
bool motorAlarm = false;
bool motorOn = true;
bool motorDir = false;
unsigned int motorSpeedRaw = 0;
unsigned int motorSpeedSet = 0;
unsigned int motorSpeedCorr = 0;
unsigned int motorSpeedSetRaw = 0;
bool motorTrueForHardBrake = false;
long lastMotorDirClick = millis();

int freqCountDuration = 500;  // ms, motor speed

int16_t flowRate = 0;
int flow_dir = 1;
int16_t flowRateMin = 0;
int16_t flowRateMax = 750;
float floatTicksTo_mLperMin = 0.052;
int16_t floatTicksToPUMPVELOCITY = 4;
float flowRateIn_mLperMin = 0;
long lastFlowDirClick = millis();


bool updateForceBar = true;
int forceBar = 0;
int lastForceBar = 0;
uint32_t forceRaw = 0;
float forceMax = 25600;
uint8_t forceOut = 0;
int forceSteps = 20;

bool updateRPMbool = false;
bool updateZbool = false;
bool updateTiltbool = false;
bool updateTipbool = false;
bool updateFlowbool = true;
bool updateWheelIndexBool = true;
bool updateFlowIdxBool = true;
bool updateRPMIdxBool = true;
bool updateTipLockBool = true;
bool updateZedLockBool = true;
bool updateSpinServoBool = true;
bool updateZedStepIdxBool = true;
bool updateTwistIdxBool = true;
bool updateRPMsetValueBool = true;
bool updateMarkPointsBool = true;

bool transmitAccessories = true;
long clickTimer_ESC = millis();
bool inClickTimer_ESC = false;
long clickTimer_pump = millis();
bool inClickTimer_pump = false;

bool firstLoop = true;

int reason = -1;

bool saveToFlash = true;
bool writeToFlashNow = false;
char filePath[] = "/data.txt";

void setup() {



	initSteppers();

	delay(100);


	reason = rp2040.getResetReason();

	switch (reason){
		case 0:
			break;
		
		case 1:
			// Power switch restart
			// Need TMC2209s powered on before boot.
			rp2040.restart();

		case 2:
			break;

		case 3: 
			break;

		case 4:
			break;

		case 5:
			break;

		default :
			break;

	}


	Serial.begin(115200);

delay(500);


	keysSerial.begin(115200);
	while (!keysSerial) {
		delay(10);
	}
	keysSerial.flush();

	dispSerial.begin(38400);
	while (!dispSerial) {
		delay(10);
	}

	mastSerial.begin(115200);

	while (!mastSerial) {
		delay(10);
	}

	mastSerial.flush();
	dispSerial.flush();	
	Serial.flush();

	pinMode(FAN_PIN, OUTPUT);
	pinMode(LAMP_PIN, OUTPUT);


	initESCMotor();

  pinMode(TWIST_STEP_PIN, OUTPUT);
  pinMode(TWIST_DIR_PIN, OUTPUT);

	pinMode(ZED_STEP_PIN, OUTPUT);
  pinMode(ZED_DIR_PIN, OUTPUT);

	updateWheelIndex(supportedIndexes[indexIndex]);
 
 
  LittleFS.begin();
  VFS.root(LittleFS);

  
  FILE *fID = fopen(filePath, "w");
  //fprintf(fID, "Hello!\n");

  fclose(fID);


  fID = fopen(filePath, "r+");
  //readSavedConfig(fID);
  //Serial.println(fID);
  fclose(fID);

}

void readSavedConfig(FILE *fID){

  int buff[8];
  int read;
  read = fread(buff, sizeof(buff), 8, fID);

  Serial.println(read);
  for (int i; i++; i < 8){
    Serial.println(buff[i]);
  }
  

}



void loop() {

	//Serial.println(lastQueryTime);

  if (firstLoop){
    homeMarkPoint();
    firstLoop = false;
  }


	if ((millis() - lastQueryTime) > frameCycleTime) {

		sendQuery();
		
		//Serial.println("in");
		//float tiltError = targetTilt_float - tiltAngle;

		lastQueryTime = millis();

    if (nLocks > 3){
      twistDirStep.move(0);
    }
    else {
      
      degreesAndDirection = shortestArcPath(targetTilt_float, tiltAngle);
      long totalStepstoMove = (degreesAndDirection)*tiltStepsPerIndexUnit;
      long stepsToMoveHere = twistErrorProportionalTerm*totalStepstoMove;
      

      if (abs(degreesAndDirection) > positionErrorTolerance) {

        nLocks = 0;
        //Serial.println(abs(degreesAndDirection), 4);

        if (twistDirStep.distanceToGo() == 0){
          
          twistDirStep.move(stepsToMoveHere);
        }
      }
      else {

        //Serial.println(nLocks);
        nLocks++;
      }


		}
	}


	if (keysSerial.available()) {

		handleKeyboardUART();
	}

	if (dispSerial.available()) {
		handleIncomingUART(DISP_IN);
	}

	if (mastSerial.available()) {
		handleIncomingUART(MAST_IN);
	}

	if (FreqCountRP2.available()) {
		
		unsigned long frequency = FreqCountRP2.read();
		// Do something with the frequency...

		motorSpeedCorr = frequency * motorNPoles;
		updateRPMbool = true;
	}

	if(twistDirStep.distanceToGo() != 0){
		twistDirStep.run();
	}



	if(zedDirStep.distanceToGo() != 0){
		zedDirStep.run();
	}

	if (inClickTimer_ESC){
		if ((millis() - lastMotorDirClick) > 2*doubleClickTime){
			// Single click
			inClickTimer_ESC = false;
			changeMotorDirection(false);
		}
	}

	if (inClickTimer_pump){
		if ((millis() - lastFlowDirClick) > 2*doubleClickTime){
			// Single click
			inClickTimer_pump = false;
			chageFlowDirection(false);
		}
	}



}

float shortestArcPath(float target, float current){

  float degAndDir = target - current;
  if (not(indexDirection)){
    degAndDir = wheelIndex - degAndDir;
  }


	if (degAndDir > 0){
		if (abs(degAndDir) > (wheelIndex/2)){
			degAndDir = (degAndDir - wheelIndex);
		}
	}
	else{
		if (abs(degAndDir) > (wheelIndex/2)){
			degAndDir = (wheelIndex + degAndDir);
		}

		
	}
	/*
	Serial.print(" ++++ ");
	Serial.print(tiltEncRaw);
	Serial.print(" ++++ ");
	Serial.println(degAndDir);
	*/

	return degAndDir;
}


void transmitFrame() {

	if (transmitAccessories){
		updateAccessories();
	}

	else{
		// Accessories are OK
	}

	


	if (updateRPMbool) {
		updateRPMValueOnScreen();
		updateRPMbool = false;
	}

	if (updateZbool) {
		updateZValueOnScreen();
		updateZbool = false;
	}

	if (updateTiltbool) {
		updateTiltAngleOnScreen();
		updateTiltbool = false;
	}

	if (updateTipbool) {
		updateTipAngleOnScreen();
		updateTipbool = false;
	}


}

void initSteppers() {
	// Motor start
	// Twist
	twistDriver.setup(twistSerial, TMC2209_SERIAL_BAUD_RATE);
	twistDriver.setHardwareEnablePin(TWIST_EN_PIN);
	twistDriver.setMicrostepsPerStep(TWIST_MICROSTEPS);
	twistDriver.setRMSCurrent(TWIST_RMS_CURRENT, 0.11);
	twistDriver.enableAutomaticCurrentScaling();
	twistDriver.enableCoolStep();
	twistDriver.setStandstillMode(TMC2209::NORMAL);
	twistDriver.enable();

	twistDriver.moveUsingStepDirInterface();

	// Z
	zedDriver.setup(zedSerial, TMC2209_SERIAL_BAUD_RATE);
	zedDriver.setHardwareEnablePin(ZED_EN_PIN);
	zedDriver.setMicrostepsPerStep(ZED_MICROSTEPS);
	zedDriver.setRMSCurrent(ZED_RMS_CURRENT, 0.11);
	zedDriver.enableAutomaticCurrentScaling();
	zedDriver.enableCoolStep();

	twistDriver.setStandstillMode(TMC2209::NORMAL);

	zedDriver.moveUsingStepDirInterface();

	//zedDriver.moveAtVelocity(ZED_RUN_VELOCITY);

	// Pump
	pumpDriver.setup(pumpSerial, TMC2209_SERIAL_BAUD_RATE);
	pumpDriver.setHardwareEnablePin(PUMP_EN_PIN);
	pumpDriver.setMicrostepsPerStep(PUMP_MICROSTEPS);
	pumpDriver.setRMSCurrent(PUMP_RMS_CURRENT, 0.11);
	pumpDriver.enableAutomaticCurrentScaling();
	pumpDriver.enableCoolStep();
	//pumpDriver.enable();

	if (PUMP_DIR) {
		pumpDriver.enableInverseMotorDirection();
	} else {
		pumpDriver.disableInverseMotorDirection();
	}
	pumpDriver.moveAtVelocity(0);

  twistDirStep.setMaxSpeed(TWIST_MAX_SPEED); //20000.0);
  twistDirStep.setAcceleration(TWIST_ACCELERATION); //40000.0);
  twistDirStep.setSpeed(TWIST_STEP_SPEED); // 200

	twistDirStep.moveTo(targetTilt);

	zedDirStep.setMaxSpeed(ZED_MAX_SPEED); //40000.0);
  zedDirStep.setAcceleration(ZED_ACCELLERATION); //100000.0);
  zedDirStep.setSpeed(ZED_STEP_SPEED); //400

	zedDirStep.move(1);



}


void initESCMotor(){

	pinMode(motorALMpin, OUTPUT);

	pinMode(motorALMpin, true);

	pinMode(motorPGpin, INPUT);
	pinMode(motorSVpin, OUTPUT);
	pinMode(motorBKpin, OUTPUT);
	pinMode(motorENpin, OUTPUT);
	pinMode(motorFRpin, OUTPUT);

	analogWrite(motorSVpin, 0);

	setMotorPins();

	FreqCountRP2.beginTimer(motorPGpin, freqCountDuration);

	changeMotorSpeed();

}

void handleIncomingUART(int inputStream) {

	// Read incoming stream from wherever
	// Parse, convert if needed
	// Update relevant value
	// Send to display

	String val;

	if (inputStream == DISP_IN) {
		// Input coming from display
		// Expect Z encoder values

		val = dispSerial.readStringUntil('\n');

	} else if (inputStream == MAST_IN) {
		// Input coming from mast
		// Expect Tip encoder, Tilt encoder, Force

		val = mastSerial.readStringUntil('\n');
		//Serial.println(val);
	}

	if (val.length() > 12){
		return;
	}

	char switchChar = val.charAt(0);


	switch (switchChar) {
		case ('w'):
			updateZEncoderSteps(val.substring(2));
      //Serial.println(val);
			updateZbool = true;
			break;

		case ('l'):
			updateTiltEncoderSteps(val.substring(2));
			updateTiltbool = true;
			break;

		case ('i'):
			updateTipEncoderSteps(val.substring(2));

			if (spinServoIdx) {
				checkServoStatus();
			}

			updateTipbool = true;
			break;

		case ('e'):
			updateForceRead(val.substring(2));

			break;


		case ('?'):
			//Serial.println("transmit");
			transmitFrame();
			break;

		case ('1') :
			//Serial.println("ACK");
			
			switch (val.charAt(2)){
				case ('a'):
				
					updateZedLockBool = false;
					break;

				case ('b'):

					updateTipLockBool = false;
					//transmitAccessories = false;
					break;

				case ('f'):
					updateFlowIdxBool = false;
					break;

				case ('F'):
					updateFlowbool = false;
					break;

				case ('N'):
					updateForceBar = false;
					break;
				
				case ('h'):
					updateRPMsetValueBool = false;
				break;

				case ('r'):
					updateRPMIdxBool = false;
					break;

				case ('s'):
					updateSpinServoBool = false;
					break;


				case ('t'):
					updateTwistIdxBool = false;
					break;


				case ('W'):
					updateWheelIndexBool = false;
					break;

				case ('z'):
					updateZedStepIdxBool = false;
					break;

        case ('M'):
          updateMarkPointsBool = false;
          break;
			}

			
			dispSerial.flush();
			break;

		case ('2') :
			//Serial.println("NAK");
			break;

		default:
			break;
			//Serial.println(val);
	}
}

bool stringIsNumeric(char *str, bool skipLastOne) {
  for (byte i = 0; str[i]; i++) {

      if (str[i] != '\0'){
        if (!digitIsNumeric(str[i])) {
              //Serial.print("!");
              //Serial.println(int(str[i]));

            if (str[i] == 13){
              if (i == 0){
                // String is blank.  Just \r.
                return false;
              }

              else if (str[i-1] == 46){
                // Truncated at decimal
                 return false;
              }

              else{
                continue;
              }
              
            }

            return false;
          }
        else{

        }
      }
  }
    return true;
  
}

boolean digitIsNumeric(char c) {
  return (isDigit(c) || ( '.' == c) || ('-' == c));
}

void updateTiltEncoderSteps(String subVal) {
	char chars[8];
	subVal.toCharArray(chars, subVal.length() + 1);

	if (stringIsNumeric(chars, true)){

		tiltEncRaw = atof(chars);
		tEncStepsToTiltValue();
	}

}

void tEncStepsToTiltValue() {
  if (indexDirection){
    tiltAngle = (float(tiltEncRaw) - tiltZero) * tiltConversion;
  }
  else{
    tiltAngle = wheelIndex - ((float(tiltEncRaw) - tiltZero) * tiltConversion);
    if ((tiltAngle) < (-wheelIndex / 2)){
      tiltAngle = wheelIndex + tiltAngle;
    }
    else if ((tiltAngle) > (wheelIndex / 2)){
      tiltAngle = tiltAngle - wheelIndex;
    }
  }
	
}

void updateForceRead(String subVal) {
	char chars[8];
	subVal.toCharArray(chars, subVal.length() + 1);

	if (stringIsNumeric(chars, true)){
		forceRaw = atof(chars);

		fRawToForceValue();	

		if (forceBar == lastForceBar){
		}
		else{
			lastForceBar = forceBar;
			updateForceBar = true;
			
			transmitAccessories = true;
			
		}

	}
	



}

void fRawToForceValue() {
	forceBar = int(forceSteps*(forceRaw / forceMax));
	//forceBar = int(forceRaw);
}

void updateTipEncoderSteps(String subVal) {
	char chars[8];
	subVal.toCharArray(chars, subVal.length() + 1);

	if (stringIsNumeric(chars, true)){
		tipEncRaw = atof(chars);
		tipEncStepsToTipValue();
	}

}

void tipEncStepsToTipValue() {
	if (tipEncRaw > 0){
		tipAngle = (float(tipEncRaw) - tipZero) * tipConversion;
	}

  //Serial.println(tipAngle);
	
}

void updateZEncoderSteps(String subVal) {
	char chars[8];
	subVal.toCharArray(chars, subVal.length() + 1);
	if (stringIsNumeric(chars, true)){
		zEncSteps = atof(chars);
		zEncStepsToZValue();
	}
}

void zEncStepsToZValue() {
	zValue = zEncSteps * zConversionFactor;
}

void sendToDisplayUART(char* x) {

	dispSerial.println(x);
	dispSerial.flush();

	//Serial.println(x);
	//Serial.flush();
}

void sendQuery() {
	//Serial.println("query");

	dispSerial.println('?');
	dispSerial.flush();

	mastSerial.println('?');
	mastSerial.flush();
}

void handleKeyboardUART() {
	uint8_t val = keysSerial.read();

	if (val == 0x0A) {
		//End of transmission

		keyboardRouter(keyString);
		lastValWasSep = true;
		k = 0;

	} else if (val == 44) {
		//Serial.println('---');
		k++;
		lastValWasSep = true;
	} else if (val == 13) {
		// do nothing
		// carriage return
	} else {

		if (lastValWasSep) {

			keyString[k] = (val - 48);
			lastValWasSep = false;
		}

		else {

			keyString[k] = keyString[k] * 10 + (val - 48);
		}
	}
}



void keyboardRouter(uint8_t keyString[]) {

	for (int i = 0; i < 8; i++) {

		char buff[8];
		char stringOut[8];

		//Serial.println(*keyString);

		switch (keyString[i]) {

			case 0:
				// skip
				break;

			case 1:
				break;

			case 2:
				break;

			case 3:
				break;

			case 4:
				//Serial.print(" 4 ");
				settingsMode();
				break;

			case 5:
				//Serial.print(" 5 ");
				incrementWheelIndex();
				break;

			case 6:
				//Serial.print(" 6 ");
				toggleCheatMode();
				break;

			case 7:
				//Serial.print(" 7 ");
				toggleZLock();
				break;

			case 8:
				//Serial.print(" 8 ");
				addPositionToList(targetTilt_float);
				break;

			case 9:
				//Serial.print(" 9 ");
				updatePositionInList(tiltMemIdx, targetTilt_float);
				break;

			case 10:
				//Serial.print(" 10 ");
				deletePositionInList(tiltMemIdx);
        
				break;

			case 11:
				//Serial.print(" 11 ");
				spinServoModeToggle();
				break;

			case 12:
				//Serial.print(" 12 ");
				changeMarkPointIndex(true);
				break;

			case 13:
				//Serial.print(" 13 ");
				changeMarkPointIndex(false);
				break;

			case 14:
				//Serial.print(" 14 ");
				homeMarkPoint();
				break;

			case 15:
				//Serial.print(" 15 ");
				toggleTiltLock();
				break;



			case 16:
				//tiltAngle = tiltAngle + tiltMult[tiltIdx];
        tiltDir = indexDirection;

				//twistDirStep.move(-100);
				changeTiltAngle(false);
				//updateTiltAngleOnScreen();
				break;

			case 17:
				tiltIdx = tiltIdx + 1;
				if (tiltIdx >= 3) {
					tiltIdx = 0;
				}
				updateTwistIdxBool = true;

				changeTwistIndex();

				break;

			case 18:
				//tiltAngle = tiltAngle - tiltMult[tiltIdx];

				//twistDirStep.move(100);
				tiltDir = not(indexDirection);
				changeTiltAngle(false);
				//updateTiltAngleOnScreen();
				break;

			case 33:
				flowRate = flowRate - 1;
				changeFlowRate();
				//updateFlowRateOnScreen();
				break;

			case 34:

				if ((millis() - lastFlowDirClick) < doubleClickTime){

					chageFlowDirection(true);
					inClickTimer_pump = false;
				}
				else{
					inClickTimer_pump = true;
				}

				lastFlowDirClick = millis();

				//chageFlowDirection(false);

				break;

			case 35:
				flowRate = flowRate + 1;
				changeFlowRate();
				//updateFlowRateOnScreen();
				break;

			case 30:
				
				RPMValue = RPMValue - 1;
				changeMotorSpeed();
				break;

			case 31:
			
				if ((millis() - lastMotorDirClick) < doubleClickTime){

					changeMotorDirection(true);
					inClickTimer_ESC = false;
				}
				else{
					inClickTimer_ESC = true;
				}

				lastMotorDirClick = millis();

				break;

			case 32:
			
				RPMValue = RPMValue + 1;
				changeMotorSpeed();
				
				break;

			case 36:

				zedDir = true;
				changeZMotorSteps();

				break;

			case 37:
				// Change multiplier
				changeZMultiplier();

				break;

			case 38:
				//zValue = zValue - zMult[zIdx];
				zedDir = false;
				changeZMotorSteps();

				//Serial.println(zValue);
				//updateZValueOnScreen();
				break;


			default:
				//Serial.print(keyString[i]);
				//Serial.println("unidentified character!");
				break;
		}



		keyString[i] = 0;
	}

}


void sendCharAndFloat(const char* s, float f, int decimals) {
	char buff[12];
	char stringFloat[12];
  uint8_t strCheck[12];

	dtostrf(f, 1, decimals, buff);

//  Serial.println(buff);

  uint8_t strChecksum = 0;
  for (int i = 0; buff[i] != '\0'; i++){
    //strCheck[i] = uint8_t(buff[i]);
    strChecksum = strChecksum + (uint8_t)buff[i];
    //Serial.println(strChecksum);
  }

	sprintf(stringFloat, "%s %d %s", s, strChecksum, buff);

  //Serial.println(stringFloat);

	sendToDisplayUART(stringFloat);
}
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

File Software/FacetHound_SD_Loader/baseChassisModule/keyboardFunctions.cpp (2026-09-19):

#include "keyboardFunctions.h"
#include "motorControl.h"
#include <Arduino.h>
#include <math.h>

static const float supportedIndexes[] = {
    1.0f, 2.0f, 6.2832f, 32.0f, 40.0f, 48.0f, 60.0f, 64.0f,
    72.0f, 77.0f, 80.0f, 81.0f, 88.0f, 91.0f, 96.0f, 98.0f,
    99.0f, 100.0f, 102.0f, 104.0f, 110.0f, 120.0f, 128.0f,
    144.0f, 192.0f, 256.0f, 360.0f, 400.0f
};

static const int N_INDEXES = 28;
static const float tiltMult[3] = { 1.0f, 0.1f, 0.005f };

static const float defaultMarkPoints[] = {
    0, 6, 12, 18, 24, 30, 36, 42,
    48, 54, 60, 66, 72, 78, 84, 90
};

static const int N_DEFAULT_MARKS =
    sizeof(defaultMarkPoints) / sizeof(defaultMarkPoints[0]);

static const float servoRelease = 120.0f;
static const float servoCapture = 105.0f;
static bool firstCrossServoThreshold = true;

static uint32_t lastMotorDirClick = 0;
static bool     inClickTimer_ESC  = false;

static const uint32_t ESC_CLICK_WINDOW_MS = 2 * DOUBLE_CLICK_MS;

static int nearestWheelIndex(float wheel)
{
    int best = 0;
    float bestErr = fabsf(wheel - supportedIndexes[0]);

    for (int i = 1; i < N_INDEXES; i++)
    {
        float e = fabsf(wheel - supportedIndexes[i]);

        if (e < bestErr)
        {
            bestErr = e;
            best = i;
        }
    }

    return best;
}

static void wrapTarget(SystemState* S)
{
    if (S->wheelIndex <= 0.0f)
        S->wheelIndex = 96.0f;

    while (S->targetTwist < 0.0f)
        S->targetTwist += S->wheelIndex;

    while (S->targetTwist >= S->wheelIndex)
        S->targetTwist -= S->wheelIndex;
}

void resetMarkPointsToDefault(SystemState* S)
{
    S->markPoints.assign(defaultMarkPoints, defaultMarkPoints + N_DEFAULT_MARKS);

    S->markIdx = 0;

    if (!S->markPoints.empty())
    {
        S->targetTwist = S->markPoints[0];
        S->targetValid = true;
        notifyTwistTargetChanged();
    }

    S->dirty = true;
}

void resetMarkPointsWithSpacing(SystemState* S, float spacing)
{
    if (!isfinite(spacing) || spacing <= 0.0f ||
        !isfinite(S->wheelIndex) || S->wheelIndex <= 0.0f)
        return;

    const size_t count = size_t(ceilf(S->wheelIndex / spacing));
    S->markPoints.clear();
    S->markPoints.reserve(count);

    for (float value = 0.0f; value < S->wheelIndex - 0.0001f; value += spacing)
        S->markPoints.push_back(value);

    S->markIdx = 0;
    if (!S->markPoints.empty())
    {
        S->targetTwist = S->markPoints.front();
        S->targetValid = true;
        notifyTwistTargetChanged();
    }

    S->dirty = true;
}

void checkServoStatus(SystemState* S)
{
    if (!S->spinServoIdx)
        return;

    if (S->tipDegrees > servoRelease)
    {
        if (firstCrossServoThreshold)
        {
            S->twistLock = 0;
            firstCrossServoThreshold = false;
            hardStopTwist(*S);
            Serial.println("@INDEX,RELEASED,TIP_SERVO_ABOVE_120");
        }
    }
    else if (S->tipDegrees < servoCapture)
    {
        if (!firstCrossServoThreshold)
        {
            S->twistLock = 1;
            firstCrossServoThreshold = true;
            notifyTwistTargetChanged();
            setTwistDriverEnabled(true);
        }
    }
}

void setSpinServoEnabled(SystemState* S, bool enabled)
{
    S->spinServoIdx = enabled ? 1 : 0;
    firstCrossServoThreshold = true;
    S->dirty = true;
}

void changeTiltAngle(SystemState* S, bool directSet)
{
    if (!S->targetValid)
    {
        if (S->twistReady)
            S->targetTwist = S->actualTwist;
        else if (!S->markPoints.empty())
            S->targetTwist = S->markPoints[S->markIdx];
        else
            S->targetTwist = 0.0f;

        S->targetValid = true;
    }

    if (!directSet)
    {
        float inc = tiltMult[S->twistIdx];

        if (S->twistDir)
            S->targetTwist += inc;
        else
            S->targetTwist -= inc;
    }

    wrapTarget(S);
    notifyTwistTargetChanged();

    if (S->twistLock)
        setTwistDriverEnabled(true);

    S->dirty = true;
}

void toggleTiltLock(SystemState* S)
{
    S->twistLock = !S->twistLock;

    notifyTwistTargetChanged();

    if (S->twistLock)
    {
        if (!S->targetValid)
        {
            if (S->twistReady)
                S->targetTwist = S->actualTwist;
            else if (!S->markPoints.empty())
                S->targetTwist = S->markPoints[S->markIdx];
            else
                S->targetTwist = 0.0f;

            S->targetValid = true;
        }

        setTwistDriverEnabled(true);
    }
    else
    {
        hardStopTwist(*S);
    }

    S->dirty = true;
}

void changeTwistIndex(SystemState* S)
{
    S->twistIdx = (S->twistIdx + 1) % 3;
    S->tiltMicrostep = tiltMult[S->twistIdx];
    S->dirty = true;
}

void changeFlowRate(SystemState* S, int delta)
{
    S->flowSetpoint += delta;

    if (S->flowSetpoint < 0)
        S->flowSetpoint = 0;

    if (S->flowSetpoint > 750)
        S->flowSetpoint = 750;

    S->dirty = true;
}
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

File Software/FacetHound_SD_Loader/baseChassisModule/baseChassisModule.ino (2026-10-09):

#include <Arduino.h>
#include <math.h>
#include <strings.h>
#include <utility>
#include <algorithm>
#include <SerialPIO.h>
#include <hardware/clocks.h>
#include <hardware/gpio.h>
#include <hardware/pio.h>
#include <hardware/irq.h>

#include "systemState.h"
#include "stateStore.h"
#include "motorControl.h"
#include "keyboardFunctions.h"
#include "sdGemLoader.h"
#include "gemGeometry.h"
#include "gemCache.h"
#include "builtinGemCuts.h"
#include "transferCheat.h"
#include "serialLinkDiagnostics.h"

// Integration trials: change one flag to true and upload only this base sketch
// to reverse that link's GPIO direction without reflashing the remote module.
constexpr bool KEYBOARD_UART_SWAP_TRIAL = false;
constexpr bool MAST_UART_SWAP_TRIAL = false;

// SerialPIO adds one reserved entry. Core 4.5.2 computes available() as
// unsigned (writer-reader) % allocation; this is correct across wrap only
// when the allocation divides 2^32. Request 2^n-1 usable bytes so the actual
// allocation is 2^n. In particular, requesting 256 allocated 257 entries:
// a full wrapped queue then reported (UINT32_MAX % 257) == 0 forever.
SerialPIO keysSerial(KEYBOARD_UART_SWAP_TRIAL ? 6 : 7,
                     KEYBOARD_UART_SWAP_TRIAL ? 7 : 6, 127);
SerialPIO dispSerial(5, 4, 255);
SerialPIO mastSerial(MAST_UART_SWAP_TRIAL ? 2 : 3,
                     MAST_UART_SWAP_TRIAL ? 3 : 2, 255);

SystemState S;
GemSdDesign activeGemDesign;
GemRuntimeGeometry activeGemGeometry;
bool activeGemLoaded = false;
int lastJobCutSent = -1;
int builtinCutIndex = 0;
int lastBuiltinCutSent = -1;
uint8_t displayVisualMode = 0; // 0 classic/unknown, 1 dynamic, 2 static
bool displayModeKnown = false;
char activeGemCacheStatus[20] = "NONE";
int pendingGemLoad = -1;
bool savedGemRestoreFailed = false;
bool savedGemRestorePending = true;
bool restoringSavedGem = false;
uint32_t pendingGemLoadMs = 0;

static const float TWIST_ENCODER_COUNTS = 4096.0f;

static const float TIP_COUNTS_CLASSIC = 131072.0f;

// uiReno's rate first; retain compatibility with already-installed fast displays.
static uint32_t displayBaud = 38400;
static bool displayBaudConfirmed = false;
static bool displayMeshRequested = false;
static uint32_t displayBaudStartedMs = 0, displayBaudProbeMs = 0;
static uint32_t displayBaudAttempt = 0;
static char displayBaudToken[48] = {};
// One short UART record per tick. The display-side SerialPIO FIFO is only 32
// bytes, so sending the whole screen as one burst causes silent line loss.
// One slot per loop opportunity, never a catch-up burst. 24 slots at 2 ms
// provide ~20 Hz per value; all fields retain equal scheduling opportunities.
static const uint32_t DISPLAY_FAST_PERIOD_MS = 2;
static const uint32_t SAVE_DEBOUNCE_MS = 500;
static uint32_t lastKeyboardActionMs = 0;
static const float MARK_MATCH_TOLERANCE = 0.0025f;

static const uint32_t TWIST_RX_TIMEOUT_MS = 120;
static const uint32_t TWIST_CHANGE_TIMEOUT_MS = 300;

char mastBuf[80];
uint8_t mastIdx = 0;

char keyBuf[16];
uint8_t keyIdx = 0;

char dispBuf[128];
uint8_t dispIdx = 0;

char usbBuf[128];
uint8_t usbIdx = 0;
uint32_t keyRxCount = 0;
uint32_t displayRxCount = 0;
uint32_t usbRxCount = 0;
uint32_t lastKeyboardRxMs = 0;
bool keyboardLinkReported = false;
uint32_t lastMastRxMs = 0;
bool mastLinkReported = false;
uint32_t mastTaskCalls = 0;
uint8_t receiveCheckRemaining = 0;
uint32_t receiveCheckDueMs = 0;
uint32_t lastDisplayRxMs = 0;
bool displayLinkReported = false;
uint32_t lastDisplayRoundTripMs = 0;
bool displayRoundTripReported = false;
bool displayTestMode = false;
bool uartTraceEnabled = false;
uint32_t lastDisplayLoopbackMs = 0;
uint32_t displayLoopbackUntilMs = 0;
bool usbStateStream = false;
uint32_t usbStatePeriodMs = 250;
uint32_t lastUsbStateMs = 0;

bool settingsMenuOpen = false;

// keyboardSettings.png programs the physical top-left key as HID A (usage 4).
static const uint8_t MENU_TOGGLE_KEY = 4;
static const uint8_t MENU_DELETE_KEY = 6;
// The former servo key is available for the second edit-tier direction.
static const uint8_t MENU_TIER_FINER_KEY = 11;
static const uint8_t TWIST_WHEEL_CCW_KEY = 16;
static const uint8_t TWIST_WHEEL_CLICK_KEY = 17;
static const uint8_t TWIST_WHEEL_CW_KEY = 18;

uint32_t lastDisplay = 0;
uint32_t lastSave = 0;
uint8_t displaySlot = 0;

uint32_t lastTwistRxMs = 0;
uint32_t lastTwistChangeMs = 0;
bool twistRxEver = false;
float lastTwistValue = NAN;

volatile uint32_t motorPgPulses = 0;
uint32_t lastRpmSampleMs = 0;

bool zEncoderValid = false;
int mastEncoderFault = -1; // -1 until a checksum-aware mast reports health.
uint32_t lastZEncoderRxMs = 0;
uint8_t zEncoderInputBits = 0;

void motorPgISR()
{
    motorPgPulses++;
}

static bool parseStrictFloat(const char* s, float* out)
{
    if (!s || !out)
        return false;

    char* endptr = nullptr;
    float v = strtof(s, &endptr);

    if (endptr == s || !isfinite(v))
        return false;

    while (*endptr == ' ' || *endptr == '\t')
        endptr++;

    if (*endptr != '\0')
        return false;

    *out = v;
    return true;
}
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

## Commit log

2025-06-04 Adding in hardware files
    [96ToothIndexWheel.stl, DisplayCaseRearPanel.dxf, TFT frame back.stl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]
2025-06-20 First round of post delivery edits.
    [faceHound_base_itsy_usb.brd, facetHound_base_module_v12.brd, facetHound_base_module_v12.sch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]
2025-06-20 Reconciling source data
    [2mmHexHolder.stl, chassis_XLRPanel.dxf, headStopLeft_20250618.stl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]
2025-07-08 Adding in templates and print aids.
    [chassisRearTemplate.dxf, motorInsetMainInset.dxf, motorInsetRing.dxf]
2025-08-26 Mostly averaging and actually fixing it
    [baseChassisModule.ino, displayModule.ino, mastModule.ino]
2025-09-19 Bug fixes and readme
    [baseChassisModule.ino]
2025-10-12 Servo mode, mark points, wheel index select
2025-10-31 Fix bug preventing negative tip angles
    [baseChassisModule.ino, displayModule.ino]
2026-05-28 updates to v8 hardware
    [bezeladapter32tft.stl, displayBezel.stl, displayMiddleLayer_v8.stl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]
2026-07-02 Adding in python files to prototype UI
2026-09-15 Fix USB demo flow and enlarge primary readouts
    [settings_menu_spyder.py]
2026-09-15 Correct pavilion poses and stabilize dynamic demo
    [gem_ui.h, settings_menu_spyder.py]
2026-09-15 Align selected facets and stage machine-like demo
2026-09-15 Tighten HUD error and status spacing
2026-09-15 Fix static facet fill and shorten display motion
    [gem_ui.h]
2026-09-15 Correct gem facing and animate classic demo
    [gem_ui.h, settings_menu_spyder.py]
2026-09-15 Fix classic chevrons and sort demo facets
    [displayModule_v6_gem.ino, settings_menu_spyder.py]
2026-09-15 Sequence demo facets without skipping
    [settings_menu_spyder.py]
2026-09-17 Integrate mast firmware with current modules
2026-09-17 Add display UART integration diagnostics
2026-09-17 Add base-only UART integration trials
2026-09-17 Add handshake-first UART diagnostics
2026-09-17 Strengthen base display UART handshake
    [baseChassisModule.ino, displayModule_v6_gem.ino]
2026-09-17 Fix AMT232B 14-bit tip decoding
    [mastModule.ino]
2026-09-17 Add motor and SD integration diagnostics
2026-09-17 Align base firmware with v9 PCB wiring
    [BaseModule.brd, BaseModule.sch]
2026-09-17 Interlock lap reversal in paused state
    [baseChassisModule.ino, displayModule_v6_gem.ino, keyboardFunctions.cpp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]
2026-09-18 Move lap Modbus link to hardware UART1
2026-09-18 Restore proven motor startup and classic RPM semantics
2026-09-18 Flush TMC setup and restore Z encoder telemetry
2026-09-18 Cap integration motion speeds and poll Z encoder
2026-09-18 Lower twist ceiling and expose raw encoders
2026-09-18 Fix encoder divider loading and blocking SD status probes
    [displayModule_v6_gem.ino, sdGemLoader.cpp]
2026-09-18 Calibrate Z jogs, restore mast startup and add original BLD probe
2026-09-18 Validate AMT23 feedback and stop runaway index corrections
    [baseChassisModule.ino, mastModule.ino, motorControl.cpp]
2026-09-18 Preserve locked holding torque, release encoder mode pulls, and isolate BLD UART
2026-09-18 Fix runtime index enable paths and clarify encoder MODE pin numbering
    [baseChassisModule.ino, keyboardFunctions.cpp, motorControl.cpp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]
2026-09-18 Reverse index motor polarity for observed moving-away fault
    [motorControl.cpp, motorControl.h]
2026-09-19 Calibrate tip convention, correct BLD pause, and expose SD gem loading over USB
    [baseChassisModule.ino, mastModule.ino, motorControl.cpp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]
2026-09-19 Use exact facet IDs and live index pose; add HUD locks and card/RPM probes
2026-09-19 Correct photographed SD pins, atomic index pose, tier ordinal and HUD state updates
    [baseChassisModule.ino, displayModule_v6_gem.ino, gem_ui.h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]
2026-09-19 Add staged SD initialization probe and conservative transfer rate
2026-09-19 Latch settled axes, expedite selection, restore lap ramp and diagnose SD mount
2026-09-19 Freeze unlocked gem pose and preserve fractional encoder averaging
2026-09-19 Correct BLD speed feedback divisor from pole pairs to poles
    [BLD510B.cpp, baseChassisModule.ino, motorControl.cpp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]
2026-09-19 Replace broken PIO SD transport and remove legacy lap RPM cap
    [GemSdSpi.h, baseChassisModule.ino, motorControl.h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]
2026-09-19 Fix imported gem orientation, reliable loading, and explicit index home
    [baseChassisModule.ino, displayModule_v6_gem.ino, gem_ui.h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]
2026-09-19 Damp index settling and confirm stopped lap before restart; skip cache writes
    [baseChassisModule.ino, displayModule_v6_gem.ino, motorControl.cpp]
2026-09-19 Cache recent display meshes and correct crown roll, girdle views, splash title
    [baseChassisModule.ino, displayModule_v6_gem.ino, gem_ui.h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]
2026-09-19 Release integration source: instant classic, live gem modes, buffered progress and Eagle harness
    [ModuleInterconnect.sch]
2026-09-20 Refine error gauge and headers; navigate full loaded facet list
    [baseChassisModule.ino]
2026-09-22 Import Gem Cut Studio GCS designs from SD and PC tools
2026-09-22 Recover missing saved gems into picker with permanent built-in option
    [baseChassisModule.ino, displayModule_v6_gem.ino, sdGemLoader.cpp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]
2026-09-22 Preserve failed-load picker selection and diagnose binary GEM reads
    [displayModule_v6_gem.ino, sdGemLoader.cpp, settings_menu.h]
2026-09-23 Fix Arduino word macro collision rejecting binary GEM footers
2026-09-23 Fix picker parent key and hide Windows system volume folder
    [displayModule_v6_gem.ino, sdGemLoader.cpp]
2026-10-09 Add pump reinitialization and local UART transmit diagnostics
2026-10-09 Recover mesh transfers after display timeouts and isolate pump bench test
2026-10-09 Restore pre-pump mesh sender and add bounded pump STEP DIR diagnostic
2026-10-09 Recover lost mesh confirmations and decouple pump test from gem loading
2026-10-09 Drive pump over verified STEP DIR path and expose base UART failure evidence
    [baseChassisModule.ino, motorControl.cpp]
2026-10-09 Restore original USB startup order after cold reset
    [baseChassisModule.ino]
2026-10-09 Remove pump UART instrumentation and restore plain SerialPIO
2026-10-09 Restore pre-pump baseline retaining only STEP DIR pump operation
2026-10-09 Probe uiReno display baud before gem restore and preserve STEP DIR pump
2026-10-09 Invert installed pump direction and capture read-only load link checkpoints
    [baseChassisModule.ino, motorControl.cpp]
2026-10-09 Skip redundant restore marker write and verify link after gem loading
    [baseChassisModule.ino]
2026-10-09 Fix SerialPIO 4.5.2 full-buffer receive deadlock with power-of-two allocations
    [baseChassisModule.ino, motorControl.cpp]

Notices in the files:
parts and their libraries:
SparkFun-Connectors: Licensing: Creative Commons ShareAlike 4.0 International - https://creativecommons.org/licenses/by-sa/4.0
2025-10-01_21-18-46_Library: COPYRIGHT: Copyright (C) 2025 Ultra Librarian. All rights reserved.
